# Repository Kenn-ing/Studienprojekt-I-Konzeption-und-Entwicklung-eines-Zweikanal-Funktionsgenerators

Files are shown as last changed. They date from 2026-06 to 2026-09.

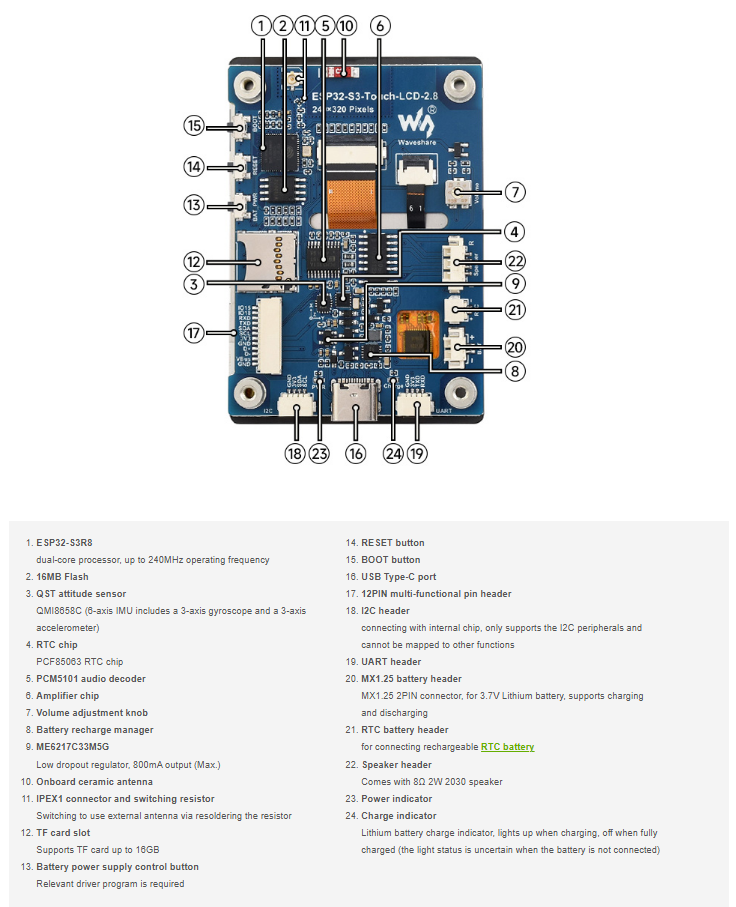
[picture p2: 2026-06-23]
docs/Pinouts/Waveshare ESP32-S3/Waveshare ESP32 S3 Ports.png

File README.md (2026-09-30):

# Studienprojekt-I-Konzeption-und-Entwicklung-eines-Zweikanal-Funktionsgenerators
 
Dieses Repository ist Teil des ersten Studienprojekts der Studenten **Dejan Dimitrijević** und **Alexander Klose** an der [**Hochschule für Wirtschaft und Recht (HWR) Berlin**](https://www.hwr-berlin.de/) in Zusammenarbeit mit den [**Berliner Wasserbetrieben AöR**](https://www.bwb.de/de/index.php).
 
| | |
|---|---|
| **Hochschulbetreuer** | Prof. Dr. Luís Fernando Ferreira Furtado |
| **Unternehmensbetreuer** | Dipl.-Ing. (FH) Thomas Freitag |
 
## Grundlegende Informationen
 
Dieses GitHub-Repository befasst sich mit der Konzeption und Entwicklung zweier Zweikanal-Funktionsgeneratoren auf Basis eines [Waveshare ESP32-S3 2,8-Zoll-Touch-LCD-Displays](https://www.waveshare.com/wiki/ESP32-S3-Touch-LCD-2.8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). Die Funktionsgeneratoren geben auf zwei Kanälen (A und B) sinus- und rechteckförmige Spannungssignale mit einstellbarer Frequenz, Amplitude und Phasenverschiebung aus. Über das Display können verschiedene Gruppen mit jeweils individuellen Parametern ausgewählt werden. Zusätzlich zur Gruppenauswahl sind Hilfestellungen zur Verwendung der Laborgeräte in die Benutzeroberfläche integriert.
 
Die Gruppenparameter für Amplitude, Frequenz, Phasenverschiebung und Signalform werden über eine CSV-Datei, die auf einer microSD-Karte gespeichert wird, eingelesen. Im Rahmen des Projekts wurden zwei unterschiedliche Implementierungsmethoden entwickelt und gegenübergestellt.
 
## Implementierungsmethode A: Signalgenerierung mittels interner Digital-Analog-Wandler eines ESP32
 
- Ausgabe der analogen Spannungswerte über die DAC-Ausgänge eines [ESP32 DevKit C V4](https://www.az-delivery.de/products/esp32-dev-kit-c-v4-nodemcu-wlan-wifi-development-board-mit-usb-c-anschluss-kompatibel-mit-arduino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), welcher per UART vom ESP32-S3 angesteuert wird.
- Die benötigten Parameter werden per UART übermittelt. Aus diesen wird ein Spannungssignal berechnet und über die internen DAC-Pins ausgegeben.

## Implementierungsmethode B: Signalgenerierung mittels Direct Digital Synthesis
 
- Ausgabe der unterschiedlichen Spannungssignale mittels zwei [AD9833-DDS-ICs](https://asset.conrad.com/media10/add/160267/c1/-/en/002993328DS00/datenblatt-2993328-analog-devices-ad9833brmz-reel7-schnittstellen-ic-dds-direct-digital-synthesizer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).
- Zur Anpassung der Ausgangsamplitude wird die Eingangsspannung eines [OPA1612](https://www.ti.com/lit/ds/symlink/opa1612.pdf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)-Operationsverstärkers über zwei digitale Potentiometer des Typs [MCP42010](https://cdn-reichelt.de/documents/datenblatt/A200/MCP42010_MIC.pdf) gesteuert.

## Repository-Struktur
 
```
├── sw/
│   ├── libraries/
|       └── lvgl/                       # lvgl Treiber
|       └── Adafruit_NeoPixel/          # NeoPixel/ws2812b Treiber
│   └── DAC_Prog/                       # Implementierungsmethode A
|       └── ESP32DevMod/                # Code für die Steuerung der Komponenten und Ausgabe der Spannung
|       └── ESP32S3/                    # Code für die Benutzeroberfläche und das Einlesen des Parameter
│   ├── DDS_Prog/                       # Implementierungsmethode B
|       └── ESP32DevMod/                # Code für die Steuerung der Komponenten und Ausgabe der Spannung
|       └── ESP32S3/                    # Code für die Benutzeroberfläche und das Einlesen des Parameter
├── proj/
│   └── EEZ Studio Projekt/             # Allgemeines EEZ Studio Projekt der Benutzeroberfläche
├── docs/
│   ├── SP-I_Klose_Dimitrijevic.pdf     # Schriftliche Ausarbeitung inklusive aller verwendeten Quellen
│   ├── Schaltpläne/                    # Schaltpläne der beiden Methoden
│   └── 3D-Design/                      # 3D Dateien und technische Zeichnungen der Gehäuse
│   └── Datenblätter/                   # Datenblätter der Komponenten
│   └── Pinouts/                        # Pinouts der Komponenten
└── README.md
```
 
## Installation
 
1. **Arduino IDE** mit [Unterstützung für ESP32 installieren](https://docs.waveshare.com/ESP32-Arduino-Tutorials/Arduino-IDE-Setup).
2. LVGL Bibliothek aus diesem Projekt herunterladen und in den `Arduino\libraries` Pfad kopieren.
3. Adafruit NeoPixel Bibliotheken aus diesem Projekt herunterladen und in den `Arduino\libraries` Pfad kopieren.
4. Je nach gewünschter Implementierungsmethode den entsprechenden Ordner ([`DAC_Prog`](https://github.com/Kenn-ing/Studienprojekt-I-Konzeption-und-Entwicklung-eines-Zweikanal-Funktionsgenerators/tree/main/sw/DAC_Prog) oder [`DDS_Prog`](https://github.com/Kenn-ing/Studienprojekt-I-Konzeption-und-Entwicklung-eines-Zweikanal-Funktionsgenerators/tree/main/sw/DDS_Prog)) in der Arduino IDE öffnen, das passende Board auswählen und flashen.
   - Für das ESP32-S3-Display müssen folgende Einstellungen in der Arduino IDE vorgenommen werden:
     - **Board:** ESP32S3 Dev Module
     - **USB CDC On Boot:** Enabled 
     - **Flash Size:** 16MB
     - **Partition Scheme:** 16M Flash (3MB APP/9.9MB FATFS)
     - **PSRAM:** OPI PSRAM
   - Für das ESP32 DevKit C V4 müssen folgende Einstellungen Arduino IDE vorgenommen werden:
     - **Board:** ESP32 Dev Module

## Nutzung
 
1. CSV-Datei mit den gewünschten Parametern für alle 30 Gruppen auf eine microSD-Karte kopieren und in das Display-Board einlegen.
3. System einschalten und die Daten nach dem die microSD-Karte erkannt wurde über den Button *Daten Laden* die Gruppenparameter einlesen.
4. Gewünschte Gruppe über die  Scroll-Liste auswählen, um das entsprechende Signal auf den Kanälen A und B auszugeben.
5. Über den Button *Start* die Signalausgabe starten.
6. Über den Button *Stop* die Signalausgabe stopen.
7. Über den Button *Hilfe* kann die Navigationsansicht aufgerufen werden, um zwischen den Hilfestellungen zu navigieren.
8. Uber den Zurück-Button in der oberen rechten Ecke gelangt man von jeder Unterseite zurück in die Navigationsansicht und von der Navigationsansicht zurück auf den Hauptbildschirm.

## Grenzwerte

| Variante | Frequenzbereich (Sinus)| Amplitudenbereich (Sinus)| Frequenzbereich (Rechteck)| Amplitudenbereich (Rechteck)|
|---|---|---|---|---|
| Implementierungsmethode A | `100 Hz - 500 Hz` | `500 mV - 1 V` | `10 Hz - 100 Hz` | `300 mV - 1,1 V` |
| Implementierungsmethode B | `1 kHz - 80 kHz` | `0,5 V - 10 V` | `10 kHz - 80 kHz` | `2 V - 10 V` |

## CSV-Dateiformat

| Spalte | Beschreibung | Einheit / Wertebereich | Beispiel |
|---|---|---|---|
| `Gruppe` | Fortlaufende ID der Parametergruppe | Ganzzahl | `1` |
| `Amplitude CH1` | Ausgangsamplitude auf Kanal 1 | mV | `410` |
| `Frequenz CH1` | Ausgangsfrequenz auf Kanal 1 | Hz | `1000` |
| `Phase CH1` | Phasenverschiebung auf Kanal 1 | ° (Grad) | `0` |
| `Signalform CH1` | Signalform für Kanal 1 | `0` = Sinus, `1` = Rechteck | `0` |
| `Amplitude CH2` | Ausgangsamplitude auf Kanal 2 | mV | `830` |
| `Frequenz CH2` | Ausgangsfrequenz auf Kanal 2 | Hz | `1000` |
| `Phase CH2` | Phasenverschiebung auf Kanal 2 | ° (Grad) | `11` |
| `Signalform CH2` | Signalform für Kanal 2 | `0` = Sinus, `1` = Rechteck | `0` |

**Beispielzeilen:**

```csv
Gruppe,Amplitude CH1,Frequenz CH1,Phase CH1,Signalform CH1,Amplitude CH2,Frequenz CH2,Phase CH2,Signalform CH2
1,410,1000,0,0,830,1000,11,0
2,830,1500,0,0,1650,45,27,0
3,240,2000,0,0,620,56,29,0
```

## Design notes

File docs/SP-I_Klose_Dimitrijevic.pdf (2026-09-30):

Studienprojekt I

### Konzeption und Entwicklung eines Zweikanal-Funktionsgenerators auf Basis eines Waveshare ESP32-S3 2,8-Zoll-Touch-LCD-Displays

Name, Vorname: | Klose, Alexander Linus
Matrikelnummer: | 77201148558
Name, Vorname: | Dimitrijevic, Dejan ´
Matrikelnummer: | 77203661440
Jahrgang: | 2024
Hochschule – Fachbereich: | HWR Berlin – Duales Studium - Technik
Fachrichtung: | Elektrotechnik
Modul: | IE-M26-6045 Studienprojekt I
Betreuer Hochschule: | Prof. Dr. Luís Fernando Ferreira Furtado
Unternehmen: | Berliner Wasserbetriebe AoR¨
Betreuer Unternehmen: | Dipl.-Ing. (FH) Thomas Freitag

Zur Kenntnis genommen:

Datum/Unterschrift Studierender

Datum/Unterschrift Unternehmensbetreuer

Datum/Unterschrift Studierender

13.07.2026

13.07.2026

20.07.2026 i.A.

Studienprojekt I | 13. Juli 2026
Ehrenwortliche Erkl ¨ | arung ¨
Wir erklaren ehrenw ¨ | ortlich: ¨
1. dass wir unser Studienprojekt selbstandig verfasst haben, ¨
2. dass wir die Ubernahme w ¨ | ortlicher Zitate aus der Literatur sowie die Verwendung der Gedanken ¨

anderer an den entsprechenden Stellen innerhalb der Arbeit gekennzeichnet haben und

3. dass wir unser Studienprojekt bei keiner anderen Prüfung vorgelegt haben.

Wir sind uns bewusst, dass eine falsche Erklarung rechtliche Folgen haben wird. ¨

Datum/Unterschrift Studierender

Datum/Unterschrift Studierender

I

13.07.2026

13.07.2026

Kurzfassung

Die Hochschule für Wirtschaft und Recht Berlin (HWR Berlin) ist eine der großen Hochschulen Berlins und bietet mit einem Portfolio von 57 Studiengangen eine große fachliche Bandbreite. Mit ¨ dem Studiengang der industriellen Elektrotechnik bietet die HWR Studierenden die Moglichkeit, ¨ eine der altesten Disziplinen im Bereich der Ingenieurswissenschaften zu erlernen. ¨

Ein essenzielles Themengebiet der Elektrotechnik stellt die Messtechnik dar. Im Studium werden die Inhalte sowie der Umgang mit Messgeraten frühzeitig vermittelt. Das vermittelte Wissen wird ¨ gegen Ende des Semesters durch eine Laborprüfung überprüft. Im Rahmen der Uberarbeitung des ¨

Moduls Messtechnik I (ET2013) soll der aktuell verwendete Funktionsgenerator (HAMEG HM 8030-4) zukünftig durch einen Zweikanal-Funktionsgenerator auf Basis eines Waveshare ESP32-S3 2,8-Zoll-Touch-LCD-Displays ersetzt werden. Dieser soll in der Lage sein, vordefinierte Parameter für Amplitude, Frequenz, Phasenverschiebung und Signalform über eine CSV-Datei zu importieren und die entsprechenden Signale an den Ausgangen bereitzustellen. ¨

Im Entwicklungsprozess wurden zwei Implementierungsmethoden, die unterschiedliche Architekturen für die Signalgenerierung verwenden, betrachtet und anschließend verglichen. Die Implementierungsmethode A nutzt für die Erzeugung der Spannungssignale die internen 8-Bit-Digital-Analog-Wandler (DAC) eines zweiten Mikrocontrollers (ESP32 DevKit C V4) und berechnet die DAC-Stützwerte rein softwaretechnisch. Die Implementierungsmethode B basiert auf der Direct Digital Synthesis (DDS) und verwendet zwei DDS-ICs (AD9833) in Kombination mit zwei digitalen Potentiometermodulen (MCP42010) und einem Operationsverstarker (OPA1612), um zwei ¨ einstellbare Spannungssignale zu erzeugen.

Beide Methoden sind in ihrer Bedienung, der Benutzeroberflache sowie in der ¨ | Ubertragung der Pa- ¨

rameter mittels UART vom HMI (Master) an einen Slave-ESP32, welcher bei beiden Methoden die Spannungsausgabe steuert, identisch. Die Varianten unterscheiden sich jedoch in ihrer Schaltungsund Softwarekomplexitat sowie in den Kosten, Abmessungen und ihrer Genauigkeit. Als bewer- ¨ tende Kriterien wurden die Erfüllung der funktionalen und nicht-funktionalen Anforderungen mit besonderem Fokus auf die Vorgaben für die Spannungsgenauigkeit (≤ ±5 %), Phasengenauigkeit (≤ ±2°) und Frequenzgenauigkeit (≤ ±5 %) herangezogen. Bei der Gegenüberstellung der Mess-

ergebnisse beider Implementierungsvarianten hat sich gezeigt, dass Implementierungsmethode B eine deutlich bessere Genauigkeit und einen deutlich großeren Frequenz- sowie Spannungsbereich ¨ aufweist (Sinus: 1 kHz - 80 kHz bei einem Amplitudenbereich von 0,5 V - 10 V, Rechteck: 10 kHz
- 80 kHz bei einem Amplitudenbereich von 2 V - 10 V). Variante A besitzt hingegen einen deutlich kleineren Frequenz- sowie Spannungsbereich (Sinus: 100 Hz - 500 Hz bei einem Amplitudenbereich von 0,5 V - 1 V, Rechteck: 10 Hz - 100 Hz bei einem Amplitudenbereich von 0,3 V -1,1 V).

Anhand aller betrachteten Gesichtspunkte ist abschließend festzuhalten, dass die Methode B trotz
der hoheren Kosten, der gr ¨ | oßeren Schaltungs- und Softwarekomplexit ¨ | at sowie der gr ¨ | oßeren Ab- ¨
messungen besser für den Einsatz im Modul Messtechnik I ET2013 geeignet ist. Methode A stellt hingegen eine geeignete Losung für Anwendungen mit geringeren Anforderungen an Genauigkeit ¨ und Funktionsumfang dar, bei denen ein besonders kompaktes Gerat erforderlich ist. ¨

II

Inhaltsverzeichnis

1 Einleitung | 1
2 Stand der Technik | 3
3 Anforderungen und Rahmenbedingungen | 6
4 Konzept und Systemarchitektur | 11

### 5 Implementierungsmethode A: Signalgenerierung mittels interner Digital-Analog-Wandler

eines ESP32 | 16
6 Implementierungsmethode B: Signalgenerierung mittels Direct Digital Synthesis | 27
7 Entwicklung der Benutzeroberflache | 43 ¨

III

7.2 Umsetzung mittels EEZ Studio und der LVGL-Library | | 43
8 Mechanisches Design | 45
8.1 Konstruktion | | 45
8.2 Materialauswahl und Fertigung | | 46
9 Fazit | 47
9.1 Vergleich | | 47
9.2 Bewertung und Empfehlung | | 49
Quellenverzeichnis | 51
Anhang | 55

IV

### 1. Einleitung

Die Metropolregion Berlin zahlt zu den bedeutendsten Wissenschaftsstandorten der Welt. Ihre ¨ Geschichte ist gepragt von Namen wie Planck, Humboldt und Einstein. Ihre heutige Stellung ¨ in der Forschung und Lehre verdankt sie den insgesamt vier Universitaten, sieben Hochschulen ¨
und über 70 außeruniversitaren Forschungseinrichtungen. ¨ | Uber 200.000 Studierende aus In- und ¨

Ausland leben und lernen in Berlin. Mit rund 12.000 Studierenden ist die Hochschule für Wirtschaft und Recht Berlin (HWR Berlin) eine in der Hochschullehre fest verankerte Große. Sie ist eine der ¨ bedeutendsten Hochschulen Berlins und bietet mit einem Portfolio von 57 Studiengangen eine große ¨ fachliche Bandbreite. Von Wirtschaftswissenschaften über Rechts- und Sicherheitsmanagement bis hin zu ingenieurwissenschaftlichen Studiengangen bietet die HWR einen engen Praxisbezug, ¨
vielfaltige Forschung, hohe Qualit ¨ | atsstandards und eine starke internationale Ausrichtung. [1] ¨

Mit dem Studiengang der industriellen Elektrotechnik bietet die HWR die Moglichkeit, eine der ¨ traditionsreichsten Fachrichtungen der Ingenieurwissenschaften zu erlernen. Im Vordergrund steht dabei die praktische Anwendbarkeit des vermittelten Wissens. Die Studierenden sollen befahigt ¨ werden, an der Entwicklung elektronischer bzw. elektrotechnischer Produkte sowie an der Planung und Leitung von Projekten der Automatisierungstechnik und Energietechnik mitzuwirken. Neben den technischen spielen dabei ebenfalls die wirtschaftlichen Aspekte stets eine zentrale Rolle. [2,
S. 3]

Bereits im ersten Semester begegnet den Studierenden im Studiengang der industriellen Elektrotechnik das Modul Messtechnik I (ET2013). Im Rahmen dieses Moduls erwerben die Studierenden tiefgreifende Kenntnisse im Umgang mit Messinstrumenten, in grundlegenden Aspekten der Planung und Realisierung von Messaufbauten sowie in der Durchführung von Fehleranalysen zur Bestimmung der resultierenden Messabweichungen. Um dieses Wissen vermitteln zu konnen, wer- ¨ den die Grundbegriffe der Messtechnik wie SI-Einheiten, Kalibrieren, Abgleichen, relative und absolute Messabweichung definiert, in der Theorie aufgearbeitet und mit Ubungen gefestigt. Des ¨

Weiteren wird auf Fehlerarten, Fehlerfortpflanzung sowie Messwertanalysen eingegangen. Zum Ende des Semesters werden die in der Theorie erlernten Inhalte in einem Laborversuch praktisch überprüft. Durch die Erstellung einer Laborarbeit konnen die Studierenden die Ergebnisse unter ¨ wissenschaftlichen Gesichtspunkten auswerten und dokumentieren. Der Umgang mit Messgeraten ¨ wie Oszilloskopen und analogen bzw. digitalen Multimetern ist dabei essenziell. [2, S. 11]

Im Zuge der Neustrukturierung des Moduls, die ebenfalls eine Uberarbeitung der aktuellen ¨

Prüfungsleistung beinhaltet, werden die Studierenden zukünftig als Teil der Laborversuche verschiedene Spannungssignale unter zahlreichen Gesichtspunkten messen und analysieren müssen. Um diesen Prozess für die große Anzahl an Arbeitsgruppen zu vereinfachen und zu standardisieren, soll auf die Verwendung eines klassischen Funktionsgenerators (Abbildung 1), der von den Studierenden manuell eingestellt werden muss, verzichtet werden. Stattdessen soll zukünftig ein Funktionsgenerator mit bereits vordefinierten Parametern für die einzelnen Gruppen und einer einfachen sowie benutzerfreundlichen Gruppenauswahl über ein Human-Machine-Interface (HMI) verwendet werden. [3]

Im Rahmen der nachfolgenden Arbeit werden der Entwurf, die Konzeption und der konstruktive

Aufbau eines solchen Funktionsgenerators auf der Grundlage eines Waveshare ESP32-S3 2.8-Zoll-Touch-LCD-Displays dokumentiert. Der Fokus der Ausarbeitung liegt dabei auf der Darstellung
des Designprozesses sowie der Probleme und Losungsans ¨ | atze bei der Entwicklung des Ger ¨ | ats. Dies ¨
umfasst ebenfalls die ausführliche Durchführung von Tests zur Validierung der Funktionsweise und den Vergleich zweier Konzepte zur Signalgenerierung unter Berücksichtigung konkreter Parameter wie der Signalqualitat, Genauigkeit und Wirtschaftlichkeit. Bei diesen zwei Konzepten handelt es ¨ sich konkret um die Signalgenerierung mittels interner Digital-Analog-Wandler (DAC) eines ESP32 und der Signalgenerierung mittels externer Direct Digital Synthesis (DDS) ICs.

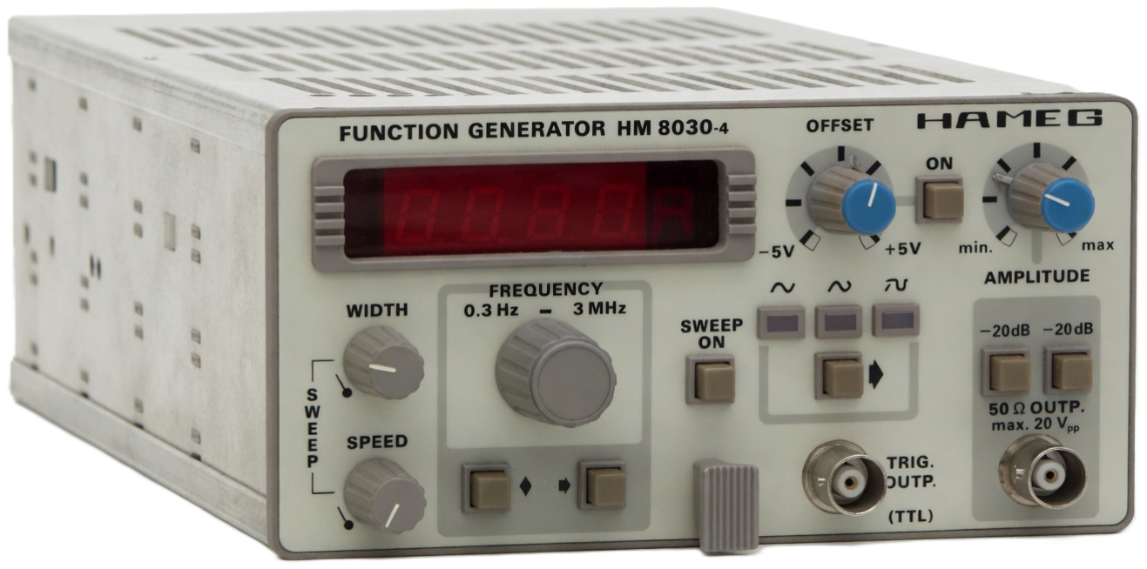
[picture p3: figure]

Abbildung 1: Aktuell verwendeter Funktionsgenerator im Messtechniklabor der HWR Berlin am Standort Lichtenberg (E-Labor 6B.158) (HAMEG HM 8030-4)[4]

### 2. Stand der Technik

### 2.1. Human-Machine-Interfaces (HMIs) in der Industrie

Im Zuge der Industrie 4.0 sind intelligente Maschinen und digitale Technologien aus modernen Produktionsumgebungen nicht mehr wegzudenken. Eine zentrale Rolle nehmen dabei HMIs ein. Durch
das Zusammenspiel von Hardware und Software ermoglichen sie dem Nutzer die ¨ | Uberwachung ¨

von Prozessen, die Visualisierung von Anlagenzustanden sowie die Anpassung relevanter Para- ¨ meter. Typische Anwendungsbeispiele reichen von der Steuerung eines Forderbandes bis hin zur ¨ Regelung der Temperatur eines Wassertanks. [5, S. 2-3]

In industriellen Anlagen werden HMIs in der Regel nicht isoliert, sondern als Bestandteil eines übergeordneten Supervisory Control and Data Acquisition (SCADA) Systems eingesetzt. Ein solches System dient der Steuerung und Uberwachung umfangreicher Anlagen oder ganzer Standorte ¨

und erfasst zugleich samtliche betriebsrelevante Daten. Das System kombiniert verschiedene Teil- ¨ systeme wie speicherprogrammierbare Steuerungen (SPS), Sensoren und Remote Terminal Units (RTUs), wahrend das HMI die Schnittstelle zwischen Nutzer und Gesamtsystem bildet. [5, S. 3] ¨ Ein praxisnahes Beispiel ist der Einsatz von HMIs bei den Berliner Wasserbetrieben (BWB). Sie
visualisieren die Fordermenge sowie die Anzeige von Pumpenzust ¨ | anden und Fehlermeldungen. ¨
[6, S. 73]

### 2.2. Mikrocontroller und Embedded-Plattformen anhand der ESP32-Familie

Mikrocontroller stellen den vorlaufigen Abschluss einer Entwicklung digitaler Logiksysteme dar, ¨ welche das grundlegende Ziel der Loslosung von der starren Verdrahtung der logischen Funktio- ¨ nen verfolgte. Diese Entwicklung begann bereits im Jahr 1965 mit der fest verdrahteten Logik oder auch hardwired logic. Hierbei wurden logische Funktionen und komplizierte sequenzielle Ablaufe ausschließlich mittels der festen Verdrahtung von Bauelementen wie Gattern, Flipflops ¨ und Schieberegistern realisiert. Das Programm ergab sich also aus der Verdrahtung der einzelnen Komponenten. Der Hauptnachteil dieses Logiktyps liegt darin, dass die logischen Funktionen bzw.
das Programm eines fertiggestellten Aufbaus kaum oder nur sehr umstandlich ver ¨ | anderbar sind. ¨
Jede Anpassung war mit enormem Aufwand und Arbeitszeit verbunden. [7, S. 1]

Mit der Entwicklung der ersten Halbleiterspeicher ROM (read only memory) und RAM (random access memory) um das Jahr 1972 wurde die Entwicklung eines neuen Logiktyps moglich. Bei der ¨ sogenannten mikroprogrammierten Logik wird ein Teil des Programms in einem Festwertspeicher und nicht durch die reine Verdrahtung von Bauelementen realisiert. Gleichzeitig wurden immer mehr flexible digitale Bausteine entwickelt, die die mikroprogrammierte Logik weiter unterstützten. [7, S. 1-2]

Durch die Entwicklung der Mikroprozessoren und Mikrocontroller im Jahr 1973 erreichte die Hardware einen universellen Charakter, wurde platzsparender und konnte in zahlreichen Geraten ¨ eingesetzt werden. Dabei liegen sowohl die Logik als auch die Sequenzen normalerweise im Programm, also der Software des Mikrocontrollers. Der Mikrocontroller ist dabei als ein hochintegrierter Baustein zu verstehen, der neben dem Mikroprozessor einen oder mehrere serielle und parallele Portbausteine, Datenspeicher und andere Sonderfunktionen an Hardware auf einem einzigen Chip vereint. Ein Mikrocontroller besitzt also im Gegensatz zum Mikroprozessor bereits zahlreiche Peripheriebausteine. Aufgrund des geringen Aufwands bezüglich des Hardwaredesigns eignen sich Mikrocontroller besonders für einfache Steuerungsaufgaben wie z. B. Aufzugs-, Waschmaschinen- und Steuerungen aller Art. Auch bei umfangreicheren Aufgaben, wie beispielsweise in Kraftfahrzeugen, finden sie Anwendung. [7, S. 2-3]

Im Bereich des Internet of Things (IoT) und in Embedded-Projekten haben sich in den letzten Jahren besonders Mikrocontroller der Firma Espressif Systems Company, welche sich als eine leistungsstarke und kostengünstige Plattform für die Entwicklung zahlreicher Anwendungen erwiesen haben, etabliert. [8] Seit der Markteinführung im Jahr 2016 vertreibt Espressif Systems seine Mikrocontroller überwiegend unter der Bezeichnung ESP32. [9]

Dabei bietet das Unternehmen zahlreiche Produktvarianten für unterschiedliche Anwendungsbereiche an. Neben den im Privatbereich weit verbreiteten Modulen wie dem ESP32-WROOM oder ESP32-MINI, die sich durch Xtensa-Prozessoren mit einem oder zwei Kernen, Taktfrequenzen von bis zu 240 MHz sowie zahlreiche Peripherieschnittstellen wie kapazitive Touchsensoren, Hall-Sensoren, Ethernet, SPI, UART, I²C und I²S auszeichnen, bietet Espressif Systems mit der

ESP32-S3-Serie ebenfalls Mikrocontroller für komplexere Anwendungen wie die Verarbeitung neuronaler Netze und die digitale Signalverarbeitung an. [10]

Durch Funktionen wie integrierte Wi-Fi- und Bluetooth-Konnektivitat, eine große Anzahl an ¨ General-Purpose-Input/Output-(GPIO)-Pins sowie die vergleichsweise hohe Rechenleistung eignen sich ESP32-Module besonders für anspruchsvollere Embedded-Projekte. [8]

### 2.3. Architekturen fur die Signalgenerierung ¨

Für die Generierung von Spannungssignalen haben sich über die Jahre einige Architekturen eta-
bliert. Sie unterscheiden sich primar in der realisierbaren Signalqualit ¨ | at, Frequenzaufl ¨ | osung, Kom- ¨
plexitat und den Kosten. Im einfachsten Fall wird ein periodisches Signal durch die softwarege- ¨ steuerte Ausgabe von vorberechneten Stützwerten über einen DAC erzeugt. [11, S. 1] In einigen
Mikrocontrollern sind solche DAC-Ausgange bereits integriert und ohne zus ¨ | atzliche Hardware ¨
nutzbar. [12, S. 45]

Eine leistungsfahigere Methode zur Signalerzeugung, die in den Bereichen der Nachrichtentechnik ¨ und allgemein in industriellen Anwendungen immer haufiger zum Einsatz kommt, ist die Direct ¨ Digital Synthesis. Bei der DDS erfolgen die Signalgenerierung und die Digital-Analog-Wandlung meist in einem einzigen dedizierten Baustein. Das Funktionsprinzip basiert auf einem Phasenakkumulator, der mit jedem Taktzyklus eines Referenztaktes um einen festen, digital programmierbaren Wert, das sogenannte tuning-word, inkrementiert wird. [11, S. 1] Gegenüber einer rein software-
basierten Losung bietet die DDS-Architektur dadurch eine deutlich feinere Frequenzaufl ¨ | osung, ein ¨
schnelles und phasenkontinuierliches Umschalten zwischen Frequenzen sowie eine hohe Unempfindlichkeit gegenüber Bauteilalterung und Temperaturveranderungen. [11, S. 3] ¨

Im Rahmen dieser Ausarbeitung werden genau diese zwei Varianten der Signalgenerierung unter verschiedenen Gesichtspunkten analysiert, miteinander verglichen und hinsichtlich ihrer Eignung für den Einsatz in einem Funktionsgenerator bewertet.

Eine detaillierte Beschreibung der Funktionsweise, des internen Aufbaus sowie der charakteristischen Kennwerte der einzelnen Verfahren zur Signalgenerierung erfolgt im Rahmen der jeweiligen Kapitel, welche die Umsetzung der jeweiligen Methoden behandeln (Kapitel 5 und Kapitel 6).

### 3. Anforderungen und Rahmenbedingungen

In den Nachfolgenden Abschnitten werden die Anforderungen bezüglich des zu entwickelnden Funktionsgenerators auf Grundlage des vorhandenen Prüfungsmaterials des Moduls Messtechnik I (ET2013) und die daraus entwickelten funktionalen und nicht-funktionalen Anforderungen beschrieben.

### 3.1. Anwendungsfall: Laborprufung ¨

Wie bereits in der Einleitung dieser Ausarbeitung erwahnt, durchl ¨ | auft das Modul Messtechnik ¨
I (ET2013) aktuell einer Neustrukturierung, die ebenfalls eine Uberarbeitung der Laborprüfung ¨

beinhaltet. Die neu entwickelten Aufgaben der Laborarbeit umfassen das Analysieren und Messen verschiedener sinus- sowie rechteckformiger Spannungssignale. Im Zuge dieser Aufgaben sollen ¨ die Studierenden zahlreiche Parameter bezüglich der verschiedenen Spannungssignale messen und berechnen. Diese Parameter sind in Tabelle 1 aufgelistet.

Konkret lauten die Aufgabenstellungen wie folgt:

•
”

Analysieren Sie die sinusformigen Spannungssignale im Oszilloskop in Kanal 1 und Kanal ¨ 2 und geben Sie die Messwerte gemaß der folgenden Tabelle ein:“ [13, S. 1] ¨
•
”

Analysieren Sie das rechteckformige Spannungssignal im Oszilloskop in Kanal 1 und geben ¨ Sie die Messwerte gemaß der folgenden Tabelle ein:“ [13, S. 2] ¨

Die Messwerte beziehen sich dabei auf die in Tabelle 1 angegebenen Parameter. Anhand dieser Parameter und Aufgabenstellungen konnten bereits zahlreiche funktionale Anforderungen aufgestellt ¨ werden. Neben den eigentlichen Aufgaben, welche die Studierenden im Rahmen der Laborarbeit erhalten und bearbeiten müssen, gibt es zudem eine vorgefertigte Tabelle, in welcher die unterschiedlichen Parameter der einzelnen Arbeitsgruppen bereits vordefiniert sind. Die einzelnen Arbeitsgruppen erhalten also nicht alle einheitliche Parameter, sondern jede Gruppe erhalt für jede ¨ Aufgabe individuelle Spannungssignale. Ein kleiner Ausschnitt aus den Tabellen für die sinussowie rechteckformigen Spannungssignale ist in den Tabellen 15 und 16 auf den Seiten 55 und 56 ¨ im Anhang zu finden. Da die Studierenden unter Verwendung des aktuellen Funktionsgenerators
die Spannungssignale selbststandig einstellen müssten, w ¨ | aren ihnen die tats ¨ | achlichen Werte bereits ¨
bekannt und ein Lerneffekt durch das gezielte Bestimmen mittels des Oszilloskops würde weitestgehend ausbleiben. Aufgrund dieser Tatsache soll der neu entwickelte Funktionsgenerator eine Moglichkeit bieten, die Spannungssignale mit den entsprechenden Werten der einzelnen Arbeits- ¨ gruppen ohne das eingreifen eines Studierenden auszugeben. Dies konnte beispielsweise über eine ¨ Comma-Separated-Values (CSV) -Datei oder über das Eingeben der einzelnen Parameter durch den Professor über eine serielle Verbindung mit einem beliebigen digitalen Endgerat erfolgen. Dabei ¨ würden die Werte für die Frequenz, Ausgangsspannung und Phasenverschiebung ohne das eingreifen der Studierenden festgelegt werden. Diese müssten nur über eine Bedienoberflache auf dem ¨ HMI ihre Arbeitsgruppe auswahlen und die Ausgabe des Spannungssignals starten und stoppen. ¨ Durch diese Struktur waren den Studierenden die vorgegebenen Parameter zu keinem Zeitpunkt ¨

Tabelle 1: Zu erhebende Messwerte der Studierenden bezüglich der sinus- sowie rechteckformigen ¨ Spannungssignale als Teil der Laborarbeit des Moduls Messtechnik I (ET2013) [13, S. 1-2]

sinusformige Spannungssignale ¨

T | Periodendauer
f | Frequenz
ω | Kreisfrequenz
u | Offset (Mittelwert)
û | Scheitelwert (max)
uˇ | Scheitelwert (min)
Ue | Spitze-Tal-Wert
Urms | Effektivwert
Δt | Phasenverschiebung in Zeit von Kanal 2
| bezüglich Kanal 1
φ[°] | Phasenverschiebung in Grad von Kanal 2
| bezüglich Kanal 1
φ[r ad] | Phasenverschiebung in Radiant von Kanal 2
| bezüglich Kanal 1
φ[%] | Phasenverschiebung in Prozent von Kanal 2
| bezüglich Kanal 1

rechteckformige Spannungssignale ¨

T | Periodendauer
f | Frequenz
ω | Kreisfrequenz
Δu = uˇ − 0 V | Offset von Null
û | Scheitelwert (max)
uˇ | Scheitelwert (min)
Ue | Spitze-Tal-Wert
Urms | Effektivwert
τ | Impulsdauer
D = τ/T | Tastgrad in Prozent (%)

bekannt, wodurch eine Anpassung oder Manipulation der Messergebnisse durch die Studierenden
verhindert werden konnte. Dadurch w ¨ | are sichergestellt, dass jede Arbeitsgruppe ausschließlich ¨
mit den ihr zugewiesenen Signalparametern arbeitet, die Versuchsdurchführung unter vergleichba-
ren Bedingungen erfolgt und die Messergebnisse tatsachlich eigenst ¨ | andig durch die Studierenden ¨
mithilfe des Oszilloskops bestimmt werden.

### 3.2. Funktionale Anforderungen

Der in Abschnitt 3.1 beschriebene Anwendungsfall sowie die vorgegebenen Aufgabenstellungen ermoglichen die Aufstellung zahlreicher funktionaler und nicht-funktionaler Anforderungen. Da ¨ sich aus den Aufgabenstellungen und den Messwerttabellen jedoch nicht alle Zielanforderungen ableiten lassen, wurde beschlossen, diese durch weitere essenzielle Punkte zu erganzen. Darunter ¨ fallen beispielsweise die Einbindung von Hilfestellungen zur Anwendung der Laborgerate (FA-12) ¨ und das Speichern der Gruppenparameter in einem Zwischenspeicher für den Fall, dass der Funktionsgenerator abstürzt oder ausgeschaltet werden sollte (FA-11). Für die Validierung der Genauigkeit und der Funktion der Funktionsgeneratoren werden dabei folgende Messwerte herangezogen: die Amplitude der Spannungssignale (entspricht dem Scheitelwert û), die Phasenverschiebung in Grad zwischen den Signalen und die Frequenz der Spannungssignale. Die Implementierung eines variablen Offsets sowie eines variablen Tastgrads wird nicht durchgeführt. Die final aufgestellten funktionalen Anforderungen sind in Tabelle 2 aufgelistet.

Tabelle 2: Funktionale Anforderungen des Projekts

Requirement number | Beschreibung
FA-1: | Das System muss zwei unabhangige analoge Ausg ¨ | ange (Kanal A, ¨
Kanal B), welche gleichzeitig genutzt werden konnen, bereitstel- ¨ len.
FA-2: | Bei den analogen Ausgangssignalen der Kanale A und B soll es ¨
sich um null symmetrische sinusformige sowie rechteckf ¨ | ormige ¨
Signale handeln.
FA-3: | Der Funktionsgenerator soll in der Lage sein, auf beiden Kanalen ¨
die Frequenz des Signals zu verandern. ¨
FA-4: | Der Funktionsgenerator soll in der Lage sein, auf beiden Kanalen ¨
die Amplitude des Signals zu verandern. ¨
FA-5: | Zwischen den beiden Ausgangssignalen muss eine definierte Pha-
senverschiebung einstellbar sein.
FA-6: | Das System muss die Verwendung vordefinierter Parametersatze ¨
unterstützen. Ein Parametersatz umfasst mindestens:
- Gruppenidentifikation
- Frequenz Kanal 1
- Frequenz Kanal 2
- Amplitude Kanal 1
- Amplitude Kanal 2
- Phasenverschiebung
- Signalform
FA-7: | Der Funktionsgenerator soll über ein HMI mit Touch-Funktion
verfügen.
FA-8: | Uber die Benutzeroberfl ¨ | ache (HMI) muss ein schnelles Umschal- ¨

ten zwischen den einzelnen Gruppen, ohne, dass das System neu gestartet werden muss, moglich sein. ¨

Requirement number | Beschreibung
FA-9: | Die Festlegung der Parameter für die Ausgangssignale der einzel-
nen Gruppen erfolgt über eine Eingabe per UART, das Einlesen einer CSV-Datei oder vergleichbare Losungen für den Import von ¨
| Parametern.
FA-10: | Uber die Benutzeroberfl ¨ | ache muss die Ausgabe der Signale auf ¨
beiden Kanalen gestartet und gestoppt werden k ¨ | onnen. Dies kann ¨
beispielsweise über dedizierte Buttons umgesetzt werden.
FA-11: | Sollte das System ausgeschaltet werden oder abstürzen und es
werden keine neuen Daten über eine microSD-Karte oder UART übergeben, werden die Parameter der letzten Sitzung bzw. An-
| wendung verwendet.
FA-12: | Auf dem HMI konnen die Studierenden Hilfestellungen für die ver- ¨
wendeten Laborgerate erhalten. Zu diesen Hilfestellungen geh ¨ | oren ¨
beispielsweise das Messen der Phasenverschiebung, der Amplitude und der Frequenz mittels des Oszilloskops.
FA-13: | Für die Navigation auf dem HMI sind dedizierte Buttons oder
anderweitige Bedienelemente implementiert.

### 3.3. Nicht-funktionale Anforderungen

Neben den funktionellen Anforderungen wurden auf der Grundlage des in Kapitel 3.1 beschriebenen Laborversuchs zudem zahlreiche nicht-funktionale Anforderungen definiert. Diese wurden, genau wie die funktionalen Anforderungen, durch erganzende Parameter erweitert. Die final auf- ¨ gestellten nicht-funktionalen Anforderungen sind in Tabelle 3 aufgelistet.

Tabelle 3: Nicht-funktionale Anforderungen des Projekts

Requirement number | Beschreibung
NFA-1: | Amplitudenfehler ≤ ±5 %
NFA-2: | Phasenfehler ≤ ±2°
NFA-3: | Frequenzfehler ≤ ±5 %
NFA-4: | Einstellbarer Frequenzbereich mind. 10 Hz bis 10 kHz. Akzeptiert: Falls dieser Frequenzbereich nicht erreicht werden kann, sollte der Frequenzbereich so groß sein, dass für alle Gruppen unterschied- liche Frequenzen festgelegt werden konnen. ¨

Requirement number | Beschreibung
NFA-5: | Der einstellbare Spannungsbereich muss es ermoglichen, dass für ¨
alle Gruppen unterschiedliche Amplitudenwerte festgelegt werden
| konnen. ¨
NFA-6: | Touch-Eingaben müssen in weniger als 100 ms für den Benutzer
| sichtbar umgesetzt und an den Ausgangen wirksam sein. ¨
NFA-7: | Der Funktionsgenerator muss einen stabilen Betrieb ohne Absturz
| oder Neustart ermoglichen. ¨
NFA-8: | Bei fehlerhaften Eingabedateien oder Hardwarefehlern fallt das ¨
| Gerat in einen definierten sicheren Zustand und es wird eine ein- ¨ deutige Fehlermeldung angezeigt.
NFA-9: | Die Stromversorgung wird über ein Netzteil oder optional über
| einen internen Akku geregelt. Falls ein Akkubetrieb vorgesehen ist:

Die Laufzeit sollte ≥ 2 h bei typischer Nutzung betragen. Zudem sollte ein Batteriemanagementsystem (BMS) implementiert sein.

NFA-10: | Der Programmcode ist strukturiert und modular aufgebaut. Einzel-
| ne Funktionen sind, um die Verstandlichkeit zu verbessern, durch ¨ Kommentare beschrieben. Die Modularitat des Programmcodes ¨ ermoglicht sowohl Wiederverwendbarkeit als auch Skalierbarkeit. ¨
NFA-11: | Der Funktionsgenerator besitzt ein labortaugliches Gehause mit ¨
eindeutiger Beschriftung der einzelnen Anschlüsse und guter Be-
| dienbarkeit.
NFA-12: | Die Hinweise zur Anwendung der Laborgerate sind verst ¨ | andlich ¨
| und gut lesbar.

### 4. Konzept und Systemarchitektur

### 4.1. Komponentenubersicht (Waveshare ESP32-S3) ¨

Das Waveshare ESP32-S3-Touch-LCD-2.8 bildet die zentrale Steuer- und Bedieneinheit des entwickelten Funktionsgenerators. Das Board basiert auf dem ESP32-S3R8-Mikrocontroller von Espressif Systems, der einen Xtensa 32-Bit LX7 Dual-Core-Prozessor mit einer Taktfrequenz von bis zu 240 MHz besitzt. Der verfügbare Arbeitsspeicher umfasst 512 KB SRAM sowie 8 MB PSRAM, erganzt durch 16 MB Flash-Speicher für die dauerhafte Ablage von Programm- und ¨ Konfigurationsdaten. [15, S. 1-2.]

Das Board verfügt über ein integriertes 2,8-Zoll-IPS-Display mit einer Auflosung von 240 ¨ | ×320 Pi-

xeln und einem kapazitiven Touchscreen, der 5-Punkt-Touch über die I²C-Schnittstelle unterstützt.

In der Abbildung 2 ist das Board in der Front- und Rückansicht abgebildet. Die Kombination aus Display und Touchscreen ermoglicht die Realisierung einer intuitiven und benutzerfreundlichen ¨ Mensch-Maschine-Schnittstelle. Darüber hinaus unterstützt das Board die Light and Versatile Graphics Library (LVGL), wodurch die Entwicklung einer strukturierten, leistungsfahigen und reak- ¨
tionsschnellen grafischen Benutzeroberflache ohne zus ¨ | atzliche Hardwarekomponenten erm ¨ | oglicht ¨
wird. [15, S. 1]

Für die Anbindung externer Peripheriebausteine stehen GPIO-, UART- sowie I²C-Schnittstellen

über dedizierte Header-Anschlüsse auf der Rückseite des HMIs zur Verfügung. Zudem verfügt das Board über einen integrierten microSD-Karten-Slot, der über den SPI-Bus angesprochen wird. Dieser würde beispielsweise das Einlesen der gruppenspezifischen Parameterdatei im CSV-Format
ermoglichen. [15, S. 2-3] Die Pinbelegung sowie alle Anschlussm ¨ | oglichkeiten des Boards sind in ¨
Abbildung 3 übersichtlich dargestellt.

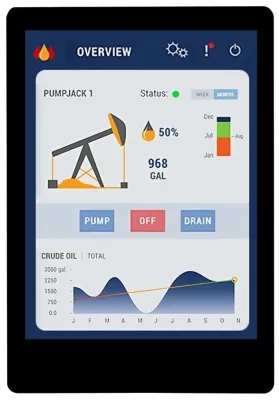
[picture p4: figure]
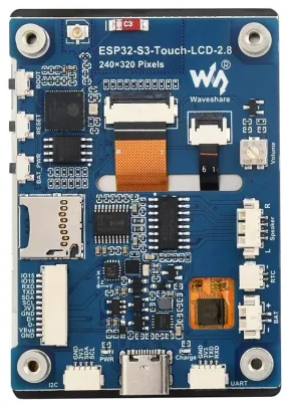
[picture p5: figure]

(a) HMI Frontansicht | (b) HMI Rückansicht

Abbildung 2: Waveshare ESP32-S3-Touch-LCD-2.8 [15, S. 5]

### 4.2. Architekturubersicht ¨

Für die Umsetzung des Funktionsgenerators wurde eine Master-Slave-Architektur, deren Aufbau in Abbildung 4 modellhaft dargestellt ist, entwickelt. Das Waveshare-HMI-Modul verfügt zwar über umfangreiche Peripherie zur Anbindung von Display, Touchcontroller und microSD-Karte, jedoch über keine für die Signalerzeugung nutzbaren DAC-Ausgange. Zudem sind durch die inter- ¨ nen Anbindungen die meisten GPIO-Pins des ESP32-S3 bereits belegt, sodass über die externen Header-Anschlüsse lediglich zwei freie GPIO-Pins (GPIO-15 und GPIO-18) verbleiben. [15, S. 5] Eine Realisierung der Signalerzeugung auf dem Master selbst, unter Verwendung externer Signalbausteine, ist daher nicht sinnvoll umsetzbar. Aus diesem Grund wird ein zweiter Mikrocontroller in das System integriert. Bei diesem handelt es sich um ein ESP32 DevKit mit zwei internen DAC-Pins an GPIO 25 und GPIO 26. Die Kommunikation zwischen beiden Controllern erfolgt über eine UART-Schnittstelle, sodass der Master den Slave durch die Ubergabe der gruppenspezifischen ¨

Parameter ansteuern kann.

Aus dieser Aufteilung ergeben sich drei wesentliche Vorteile. Erstens entsteht eine klare funktionale Trennung zwischen Bedienlogik und Signalerzeugung, wodurch beide unabhangig voneinander ¨
entwickelt und getestet werden konnen. Zweitens wird die Echtzeitf ¨ | ahigkeit des Systems verbessert, ¨
da die zeitkritische Signalausgabe nicht durch Touch-Ereignisse oder das Rendern der grafischen
Benutzeroberflache unterbrochen wird. Drittens erh ¨ | oht die Aufteilung die Modularit ¨ | at des Ge- ¨
samtsystems. Der Master bleibt für unterschiedliche Implementierungsansatze identisch, w ¨ | ahrend ¨
die Signalerzeugung auf der Slave-Seite ausgetauscht werden kann.

Die Rollenverteilung ergibt sich somit unmittelbar aus diesem Konzept. Der Master übernimmt


Abbildung 3: Pinbelegung und Anschlussmoglichkeiten des Waveschare ESP32-S3-Touch-LCD- ¨ 2.8 [16]

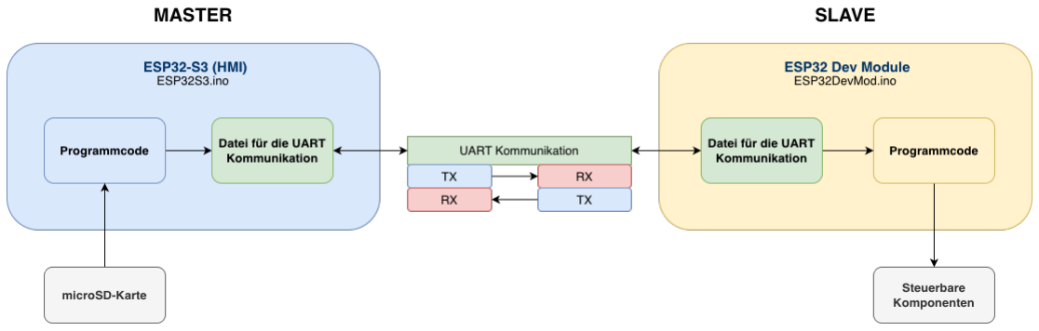
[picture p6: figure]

Abbildung 4: Modellhafte Darstellung des Master-Slave-Prinzips

die Darstellung der Benutzeroberflache, das Einlesen und Verarbeiten der Parameterdatei von ¨
der microSD-Karte sowie die Ubergabe der ausgew ¨ | ahlten Parameter an den Slave. Der Slave ¨
ist hauptsachlich für die Erzeugung der Spannungssignale gem ¨ | aß den empfangenen Vorgaben ¨
zustandig. ¨

### 4.3. Komponentenauswahl (ESP32 DevKit C V4)

Für die Realisierung der Signalerzeugung wurde das ESP32 DevKit C V4 der Firma AZ-Delivery (Abbildung 5) als zweiter Mikrocontroller ausgewahlt. Das DevKit basiert auf dem ESP32- ¨ WROOM-32-Modul, welches eine Taktfrequenz von bis zu 240 MHz besitzt. Der verfügbare Arbeitsspeicher umfasst 520 KB SRAM, erganzt durch 4 MB SPI-Flash für die Ablage von Pro- ¨ grammcode und Konfigurationsdateien. [17, S. 2]

Entscheidend für die Auswahl dieses Moduls sind die beiden 8-Bit-Digital-Analog-Wandler an GPIO 25 und GPIO 26, die für die Umsetzung der in Kapitel 5 beschriebenen Implementierungsmethode A unverzichtbar sind. Da weder das Waveshare-HMI noch leistungsstarkere Varianten der ¨ ESP32-S3-Serie über derartige DAC-Ausgange verfügen, stellt das ESP32-WROOM-32-Modul ¨ innerhalb der ESP32-Familie eine technisch konsistente und zugleich kostengünstige Losung dar. ¨

Neben den DAC-Pins bietet das DevKit eine große Anzahl an frei verfügbaren GPIO-Pins sowie die

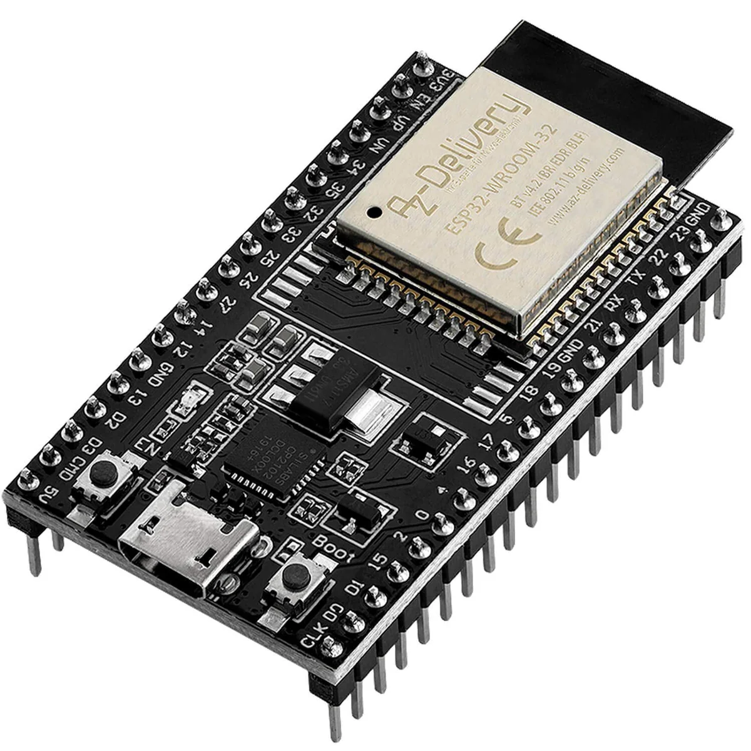
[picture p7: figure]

Abbildung 5: ESP32 DevKit C V4 der Firma AZ-Delivery [18]

für beide Implementierungsmethoden erforderlichen Schnittstellen. Uber die UART-Schnittstelle ¨

erfolgt der Empfang der gruppenspezifischen Parameter vom Master, wahrend die SPI-Schnittstelle ¨ in der in Kapitel 6 beschriebenen Implementierungsmethode B zur Ansteuerung der externen Komponenten genutzt wird. [17, S. 16-17] Mit einem Betriebsspannungsbereich von 3,0 V bis 3,6 V lasst sich das Modul direkt über die 3,3-V-Versorgung des Waveshare-Boards versorgen, ¨ sodass für den Slave keine eigenstandige Spannungsversorgung erforderlich ist. [17, S. 26] ¨

### 4.4. Datenubertragung zwischen Master und Slave ¨

Wie in Abschnitt 4.2 beschrieben, übernimmt der Master die Verwaltung der gruppenspezifischen Parameter, wahrend der Slave für die Erzeugung der Spannungssignale verantwortlich ist. Damit ¨ der Slave die Parameter ausgeben kann, müssen diese zunachst auf dem Master eingelesen und ¨ anschließend über die UART-Schnittstelle übergeben werden. Der gesamte Datenfluss gliedert sich in die drei Phasen: Einlesen, Verarbeitung und Ubertragung. ¨

Die Parameter der einzelnen Arbeitsgruppen werden auf einer microSD-Karte in einer CSV-Datei abgelegt. Jede Zeile beschreibt eine Arbeitsgruppe und enthalt neun durch Kommata getrennte Wer- ¨ te: die Gruppen-ID sowie jeweils Amplitude (in mV), Frequenz (in Hz), Phase (in °) und Signalform

(0 = SIN, 1 = SQU) für die beiden Kanale. Die erste Zeile der Datei dient als Header und enth ¨ | alt die ¨
Spaltenbezeichnungen. Tabelle 4 zeigt den Inhalt der verwendeten Datei mit drei Beispielgruppen. Die Wahl des CSV-Formats begründet sich durch dessen einfache Handhabung. Parametersatze ¨ lassen sich ohne großen Aufwand in einem beliebigen Tabellenkalkulationsprogramm (z.B. Excel) erstellen und anpassen. Zudem ist das zeilenorientierte Format ressourcenschonend, da wahrend ¨ des Einlesens stets nur eine Zeile im Arbeitsspeicher gehalten werden muss.

Sobald der Nutzer auf dem HMI die Funktion zum Laden der Parameter auslost, wird über ¨ den Master der SPI-Bus initialisiert, die Datei geoffnet und zeilenweise eingelesen. Dabei wird ¨ die Header-Zeile übersprungen und jede weitere Zeile wird in eine Datenstruktur des Typs SignalGroup überführt und in einem Array im Arbeitsspeicher des Masters abgelegt. Die eigentliche Zerlegung einer Zeile übernimmt die in Listing 1 auf Seite 57 im Anhang gezeigte Funktion csv parse line(). Sie wertet die Zeichenkette mittels csv read value() feldweise von links nach rechts aus und konvertiert die Werte je nach Datentyp über atof() bzw. atoi(). Vor dem Schreiben der Variablen wird die Struktur mittels memset() mit Nullwerten initialisiert. Die maximale Anzahl an Gruppen ist, um den Speicherverbrauch zu minimieren, durch die Konstante MAX GROUPS begrenzt.

Tabelle 4: Signalparameter – drei Beispielgruppen aus der CSV-Datei

CH1 | CH2
Gruppe | Ampl. | Freq. | Phase | Form | Ampl. | Freq. | Phase | Form
1 | 410 | 50 | 0 | 0 | 830 | 50 | 90 | 0
2 | 1500 | 100 | 0 | 1 | 1000 | 100 | 45 | 1
3 | 620 | 500 | 0 | 1 | 750 | 500 | 20 | 1

Nachdem die Parameter aller Gruppen eingelesen wurden, werden diese an den Slave übertragen. Das Ubertragungsprotokoll ist text- und zeilenbasiert aufgebaut. Sowohl der serielle Monitor des ¨

Masters als auch der des Slaves geben samtliche Nachrichten im Klartext aus, was die Fehlersuche ¨ wahrend der Entwicklung erheblich vereinfacht. ¨

Eine vollstandige ¨ | Ubertragung gliedert sich in drei Phasen: ¨
1. Ankundigung: ¨ | Der Master sendet die Nachricht COUNT:n, wobei n für die Anzahl der
folgenden Gruppen steht. Der Slave kann dadurch den erforderlichen Speicher reservieren
und überprüfen, ob die anschließende Ubertragung vollst ¨ | andig empfangen wurde. ¨
2. Parameter: Für jede Gruppe wird eine Zeile mit allen neun Parametern im Format

G:<id>,A1:<Wert>,F1:<Wert>,P1:<Wert>,S1:<Wert>,A2:... übertragen.

3. Abschluss: Mit der Nachricht DONE signalisiert der Master das Ende der Ubertragung. ¨

Alle Nachrichten werden vom Slave mit einem ACK (Acknowledge) oder NACK (Negative Acknowledge) quittiert. Der Master wartet für jeden gesendeten Datensatz maximal 500 ms auf eine
Bestatigung, bevor die ¨ | Ubertragung als fehlgeschlagen erkannt und abgebrochen wird. Durch die- ¨

sen Mechanismus kann ein nicht reagierender Slave identifiziert werden und eine Fehlermeldung kann ausgegeben werden.

Neben der Ubertragung der Gruppenparameter, werden zus ¨ | atzlich zwei weitere Befehle vom Master ¨

übermittelt. Mit dem Befehl START:<id> fordert der Master den Slave auf, die Signalausgabe für die Gruppe mit der angegebenen ID zu starten. Mit der Nachricht STOP soll die aktive Ausgabe beendet werden. Beide Befehle erwarten ein ACK vom Slave als Bestatigung. Diese Aufteilung der ¨ Kommunikation in einen einmaligen Initialisierungs- und einen wiederkehrenden Steuerungsteil vermeidet überflüssigen Datenverkehr wahrend der Nutzung, da die einmal übertragenen Parameter ¨ im Speicher des Slaves verbleiben und über die Gruppen-ID jederzeit angesprochen werden konnen. ¨ Abbildung 12 auf der Seite 59 im Anhang zeigt die Aufnahmen der drei Phasen einer vollstandigen ¨ Ubertragungssequenz. ¨

### 5. Implementierungsmethode A: Signalgenerierung mittels interner Digital-Analog-

Wandler eines ESP32

In diesem Kapitel wird die erste Methode zur Signalerzeugung vorgestellt. Ausgehend von der in Kapitel 4.2 beschriebenen Master-Slave-Aufteilung werden die Umsetzung des Kommunikationsprotokolls sowie die Generierung der Spannungssignale beschrieben. Der Schwerpunkt liegt auf der Uberprüfung der in Kapitel 3 erarbeiteten Anforderungen an das System. Die durchgeführten Tests ¨

bilden zugleich die Grundlage für den spateren Vergleich der beiden Implementierungsans ¨ | atze in ¨
Kapitel 9.

Die Verarbeitung der Parameter sowie die Ausgabe der Signale wurde softwareseitig in der Programmiersprache C++ umgesetzt. Als Entwicklungsumgebung wurde die Arduino IDE (Version 2.3.X) gewahlt. Diese bietet eine Vielzahl bereits vorhandener Bibliotheken und verfügt über eine ¨ große globale Nutzerbasis, wodurch sowohl die Entwicklung als auch die Fehlersuche erleichtert werden. [19]

### 5.1. Kommunikationsprotokoll und Schnittstellendesign

Wahrend in Abschnitt 4.4 der Datenfluss aus Sicht des Masters dargestellt wurde, beschreibt dieses ¨ Unterkapitel die slaveseitige Umsetzung des Protokolls auf dem ESP32 DevKit. Der Fokus liegt auf der Darstellung der Empfangslogik, dem Parsing der eingehenden Nachrichten sowie dem Zusammenspiel zwischen den UART-Schnittstellen.

Die Empfangslogik teilt sich beim Slave in zwei Zustande auf. Diese sind im Code durch die bool- ¨ sche Variable receiving realisiert worden. Im Grundzustand ist die Variable auf false gesetzt und wartet auf eine Count:<id>-Nachricht, die den Beginn einer neuen Parameterübertragung signalisiert. Mit dem Empfang der Nachricht setzt der Slave die Variable receiving auf true und beginnt, die einzelnen Gruppen einzulesen. Diese werden zunachst in einem internen Puffer ¨ zwischengespeichert. Nach Erhalt der Nachricht DONE ist die Ubertragung beendet und der Slave ¨

speichert alle Gruppenparameter im Non-Volatile Storage (NVS). Zuletzt wird der Slave wieder in den Grundzustand (receiving = false) zurückgesetzt.

Die Steuerbefehle START:<id> und STOP sind bewusst zustandsunabhangig implementiert. Sie ¨
greifen ausschließlich auf den NVS zu, in welchem die Datensatze gespeichert sind. Somit k ¨ | onnen ¨
diese Befehle immer verarbeitet werden und sind getrennt von der Datenübertragung. Diese Trennung ist die unmittelbare technische Umsetzung der Anforderung FA-11. Da die im NVS gespeicherten Daten auch nach einem Neustart oder einem Stromausfall verfügbar sind, kann der Master eine zuvor übermittelte Gruppe jederzeit erneut starten, ohne die Parameter ein zweites Mal übertragen zu müssen. Tabelle 5 fasst die vom Slave erkannten Nachrichten, die ausgeloste ¨ Reaktion sowie die jeweilige Quittierung zusammen.

Die eigentliche Uberführung einer empfangenen Parameterzeile in die in Abschnitt 4.4 eingeführte ¨

Datenstruktur SignalGroup übernimmt die Funktion parse group(). Sie verwendet einen festen sscanf-Format-String, der exakt die neun Felder einer Gruppenzeile beschreibt. Der Rückgabewert von sscanf entspricht der Anzahl der erfolgreich eingelesenen Felder und dient unmittelbar als

Tabelle 5: Verarbeitete Nachrichten des Slaves, ausgeloste Aktion und Quittierung. ¨

Nachricht | Aktion | Antwort
COUNT:<n> | Anzahl prüfen (0 < n ≤ MAX GROUPS), Zahler ¨ zurücksetzen, Zustand receiving = true | ACK / NACK
G:<id>,A1:...,S2:<Wert> | Zeile parsen, Werte in den RAM-Puffer übernehmen | ACK / NACK
DONE | Vollstandigkeit prüfen, RAM-Puffer in den NVS ¨ schreiben, Zustand receiving = false | ACK / NACK
START:<id> | Gruppe aus NVS laden, DAC-Ausgabe starten | ACK / NACK
STOP | DAC-Ausgabe beenden, Kanale auf den DAC- ¨ Mittelwert (128) zurücksetzen | ACK

Plausibilitatsprüfung. Werden nicht alle neun Felder erkannt, gilt die Zeile als ungültig, es wird ¨ eine Fehlermeldung über den seriellen Monitor ausgegeben und die Zeile an den Master mit einem NACK quittiert. Erst bei einer vollstandig erkannten Zeile werden die eingelesenen Werte in die ¨ Variablen der SignalGroup-Struktur übernommen. Listing 2 auf Seite 58 im Anhang zeigt die Funktion in ihrer im Quellcode vorliegenden Form.

Die SignalGroup-Strukturen werden jedoch nicht unmittelbar dauerhaft gespeichert. Eine zentrale Designentscheidung des Slaves besteht vielmehr darin, eingehende Gruppenzeilen zunachst ¨ in einem RAM-Puffer der festen Große ¨ MAX GROUPS zwischenzuspeichern und erst nach Empfang der abschließenden DONE-Nachricht in den NVS zu übernehmen. Dadurch bleibt der bisher gespeicherte Parametersatz auch dann unversehrt, wenn eine Ubertragung mitten in der Sequenz ¨

abbricht, beispielsweise weil das Verbindungskabel gelost wird oder der Master einen unerwarteten ¨
Reset durchlauft. Erst eine vollst ¨ | andige und fehlerfreie ¨ | Ubertragung führt zu einer Ver ¨ | anderung ¨

des persistenten Speichers. Diese Pufferung und Persistierung ist in der Datei save data.cpp umgesetzt.

Mit dem Empfang einer gültigen START:<id>-Nachricht endet der Aufgabenbereich des Kommunikationsteils. Die Funktion dac start output(), deren interne Funktionsweise in Abschnitt 5.3 ausführlich beschrieben wird, übernimmt die in der SignalGroup-Struktur enthaltenen Parameter und beginnt mit der Ausgabe der entsprechenden Spannungssignale an den beiden DAC-Pins.

### 5.2. Schaltungsentwicklung

In diesem Abschnitt wird der schaltungstechnische Aufbau der Implementierungsmethode A zur Signalerzeugung beschrieben. Der vollstandige Schaltplan ist in Abbildung 13 auf Seite 60 im ¨ Anhang zu finden.

Die Spannungsversorgung des HMIs betragt 5 V DC und erfolgt über die integrierte USB-C- ¨ Schnittstelle. Das HMI (Master) versorgt anschließend den Slave mit 3,3 V. Eine gemeinsame Masseverbindung zwischen den beiden Boards stellt das für die UART-Kommunikation erforderliche Bezugspotential sicher. Die UART-Pins des Masters, U0TXD (GPIO 43) und U0RXD (GPIO

44), sind mit den entsprechenden Pins des Slaves, U2TXD (GPIO 17) und U2RXD (GPIO 16), gekreuzt verbunden, sodass TX jeweils auf RX trifft.

Die internen DACs des ESP32 konnen keine negativen Spannungswerte ausgeben. Somit sind die ¨ Spannungssignale nicht symmetrisch um den Nullpunkt und weisen einen Gleichspannungsoffset auf. Deswegen ist an den beiden DAC-Ausgangen des Slaves je ein Keramik-Koppelkondensator ¨ mit einer Kapazitat von 100 nF in Reihe geschaltet. Diese entfernen den Gleichspannungsanteil ¨ des Ausgangssignals und zentrieren das Signal um den Nullpunkt, wie es in FA-2 gefordert ist.

Der Koppelkondensator bildet gemeinsam mit dem Eingangswiderstand des Oszilloskops von R = 1 MΩ einen Hochpassfilter erster Ordnung. [23, S. 22] Dessen Grenzfrequenz fg berechnet sich nach der Formel 1.

fg =

1

2π · R · C

=

1
2π · 1 MΩ · 100 nF
≈ 1, 59 Hz | (1)

Die Grenzfrequenz liegt damit unterhalb des in der NFA-4 festgelegten Nutzfrequenzbereichs. Die
Dampfung des Nutzsignals l ¨ | asst sich über den Amplitudengang des Hochpasses nach Formel 2 bei ¨
einer Frequenz von 10 Hz bestimmen. [25, S. 241-243]

A = 20 · log10

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
= 20 · log10

©
«

1
√︄
1 +
1,59 Hz

10 Hz 2

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
≈ −0,11 dB. | (2)
Die Dampfung ist somit ab einer Frequenz von etwa 10 Hz vernachl ¨ | assigbar. Lediglich im Bereich ¨
der niedrigsten getesteten Frequenz (1 Hz) ist mit einer merklichen Dampfung sowie einer durch den ¨ Hochpass verursachten Phasenverschiebung zu rechnen, was bei der Bewertung der Messergebnisse in Abschnitt 5.4 entsprechend zu berücksichtigen ist.

Die Wahl eines Keramikkondensators ist durch dessen geringe Eigenverluste (niedriger ESR), die hohe Verfügbarkeit sowie das stabile Frequenzverhalten begründet. Keramikkondensatoren weisen über einen weiten Frequenzbereich eine niedrige Impedanz auf, sodass das Wechselspannungssignal ohne nennenswerte Verfalschung übertragen wird. [24] ¨

Zusatzlich wurde zur Rückmeldung an den Anwender ein adressierbarer LED-Streifen des Typs ¨ WS2812B, der über GPIO 15 des Slaves angesteuert und für visuelles Feedback, sowie ein passiver Buzzer für akustische Rückmeldung, welcher über GPIO 15 des Masters angesteuert wird, integriert. Diese Komponenten dienen ausschließlich der Benutzerinteraktion und haben keinen Einfluss auf die Signalqualitat. Der adressierbare LED-Streifen signalisiert dem Anwender den ¨ aktuellen Ausgabezustand. Im Stopp-Zustand leuchtet er grün, sobald eine Gruppe gestartet und ein Spannungssignal ausgegeben wird, wechselt die Farbe auf Rot. Der Buzzer erzeugt einen Ton,
wenn eine Schaltflache auf dem Display bet ¨ | atigt wird, sowie wenn die microSD-Karte eingeführt ¨
oder entfernt wird.

### 5.3. Ansteuerungslogik

Die Implementierung der Signalerzeugung und Geratesteuerung auf dem Slave-ESP32 wurde ¨ mittels vier dedizierten C++-Dateien, einer zentralen Ino-Datei und fünf Header-Dateien umgesetzt. Die Auflistung der einzelnen Dateien sowie ihre Funktion ist in Tabelle 6 zu finden.

Die Erzeugung der periodischen Spannungssignale wird durch den Mikrocontroller übernommen,
indem dieser in regelmaßigen Abst ¨ | anden vorberechnete Stützwerte über die zwei internen 8-Bit- ¨
DAC-Kanale ausgibt. Die Generierung der Signalwerte erfolgt vollst ¨ | andig durch den Programm- ¨
code des Mikrocontrollers, wahrend der DAC ausschließlich die Funktion eines spannungsausge- ¨ benden Endglieds übernimmt.

Die internen DACs des ESP32 sind nach dem Prinzip des sogenannten R-String-DAC aufgebaut. Eine Reihenschaltung von 256 gleich großen Widerstanden liegt zwischen der Referenzspan- ¨ nung Vr e f und Masse und bildet einen Spannungsteiler mit 256 Abgriffen. Ein digital gesteuertes Multiplexer-Netzwerk wahlt anhand des 8-Bit-Eingangswortes den entsprechenden Abgriff aus, ¨ dessen Spannung anschließend durch einen integrierten Verstarker niederohmig am Ausgangspin ¨
bereitgestellt wird. Beide DAC-Kanale arbeiten unabh ¨ | angig voneinander und k ¨ | onnen simultan ¨
mit unterschiedlichen Werten beschrieben werden. Als Referenzspannung dient die Versorgungsspannung VDD3P3 RTC, die im Datenblatt mit 3,3 V angegeben ist. [20, S. 745-746] [21, S. 70]

Die am Ausgang anliegende Spannung berechnet sich für jeden Kanal nach Formel 3, wobei Vr e f die Referenzspannung und digiV alue den geschriebenen digitalen Wert im Bereich von 0 bis 255 bezeichnet. [22]

Tabelle 6: Ubersicht der Dateien für die Ansteuerung der Komponenten und Ausgabe der Span- ¨ nungen des Slave-ESP32

Dateiname | Funktion
ESP32DevMod.ino | Hauptdatei. Verantwortlich für die Verknüpfung
der einzelnen Unterdateien und das Ausführen
| der Funktionen.
dac output.cpp und dac output.h | Dateien für die Steuerung der
Spannungsausgabe über die internen DAC-Pins, falls diese über das HMI gestartet oder gestoppt wird.
ws2812b.cpp und ws2812b.h | Dateien für die Ansteuerung des adressierbaren
| LED-Streifens.
save data.cpp und save data.h | Dateien für das Speichern der Gruppenparameter im NVS.
signal config.h | Datei für die Definition der Signalkonfiguration
| der UART-Ubertragung. ¨
uart.cpp und uart.h | Dateien für die Umsetzung der
UART-Kommunikation zwischen dem HMI (Master) und dem ESP32 DevKit (Slave).

VOut =

Vr e f · digiV alue
255 | (3)

Aus dieser Beziehung ergibt sich die kleinste auflosbare Spannungsstufe nach Formel 4. ¨

Vste p =

Vr e f
2

n − 1

=

3,3 V
255 ≈ 12,9 mV | (4)
Eine messtechnische Uberprüfung der tats ¨ | achlichen Ausgangsspannung am DAC-Pin zeigte je- ¨

doch, dass die realen Spannungswerte von dieser theoretischen Berechnung abweichen. Bei einem Eingangswort von 0 wurde am Oszilloskop eine Restspannung von etwa 0,1 V gemessen. Bei einem Eingangswort von 255 erreichte die Ausgangsspannung lediglich 3,127 V anstelle der erwarteten 3,3 V. Um die Signalgenerierung ausschließlich im linearen Bereich des DAC durchzuführen, wurde der nutzbare Spannungsbereich softwareseitig auf 0 V bis 3 V begrenzt.

Da der DAC für einen gegebenen Eingangswert lediglich eine statische Spannung ausgibt, muss der Mikrocontroller die zur jeweiligen Signalform gehorenden Werte fortlaufend berechnen und ¨ in den DAC schreiben. Hierfür wurde auf dem Slave ein softwarebasierter numerischer Oszillator nach dem Phaseninkrement-Verfahren implementiert. Dieser greift auf dasselbe Grundprinzip, das auch der in Kapitel 6 beschriebenen DDS zugrunde liegt, zurück, führt die Berechnung jedoch vollstandig im Programmcode auf dem ESP32 durch. ¨

Für jeden Kanal wird hierzu eine Phasenvariable φacc eingeführt, die in jedem Durchlauf der Hauptschleife um ein Phaseninkrement entsprechend der vergangenen Zeit Δt und der gewünschten Frequenz f erhoht wird. Formel 5 zeigt die Berechnung der Phasenvariable. ¨

φacc [n] = φacc [n − 1] + 2π · f · Δt | (5)

Die Zeitdifferenz Δt wird über die Funktion micros() zwischen zwei Schleifendurchlaufen ¨ bestimmt, sodass keine fest definierte Sample-Rate erforderlich ist. Sobald φacc den Wert 2π überschreitet, wird der Wert der Phasenvariable um eine volle Periode reduziert, damit diese
nicht unbegrenzt wachst. Anschließend wird der momentane Signalwert in Abh ¨ | angigkeit der ¨
ausgewahlten Signalform berechnet. Sinusf ¨ | ormige Signale entstehen durch die Auswertung von ¨
sin(φacc) über die C-Standardfunktion sinf(), wahrend rechteckf ¨ | ormige Signale durch die Aus- ¨
wertung des Vorzeichens des Sinus erzeugt werden. Diese Losung kommt ohne eine separate ¨ Tabellenstruktur aus, wie sie etwa bei DDS-ICs verwendet wird. Dies geht jedoch zu Lasten der erreichbaren Ausgangsfrequenz, da pro Abtastwert eine vollstandige Gleitkommarechnung durch- ¨ geführt werden muss.

Die in Anforderung FA-5 geforderte Phasenverschiebung zwischen den beiden Kanalen wird durch ¨ eine unterschiedliche Initialisierung der jeweiligen Phasenvariable realisiert. Beim Start einer Gruppe werden φacc,1, sowie φacc,2 mit den in Grad vorgegebenen und in Radiant umgerechneten Phasenwerten initialisiert. Das Vorzeichen des Phasenwertes wird dabei invertiert, sodass ein positiver Vorgabewert einer Nacheilung des betreffenden Kanals entspricht. Anschließend wird die
Zeitbasis für beide Kanale neu gesetzt, sodass beide Kan ¨ | ale synchron starten und der vorgegebene ¨

Phasenversatz exakt eingehalten wird.

Der interne DAC kann ausschließlich positive Spannung im Bereich von 0 V bis 3 V (nach durchgeführter Kalibrierung) ausgeben. Der Laborversuch benotigt jedoch um den Nullpunkt ¨ symmetrische Signale. Um dies zu erreichen, wird der Mittelwert des Aussteuerungsbereichs als virtueller Nullpunkt definiert. Da der DAC den ganzzahligen Wertebereich von 0 bis 255 abbildet, liegt dieser rechnerische Mittelwert bei 127,5. Alle Signalwerte schwingen symmetrisch um diesen Mittelwert, sodass am DAC-Pin ein Wechselspannungssignal anliegt, das mit einem Gleichspannungsoffset von etwa 1,5 V überlagert ist. Ein in Reihe liegender Kondensator blockiert den Gleichspannungsanteil und gibt nur den Wechselspannungsanteil an den Ausgang weiter. Damit steht eine nutzbare Amplitude von ±1, 5 V um den Nullpunkt am Ausgang des Funktionsgenerators zur Verfügung. Die Umrechnung der gewünschten Amplitude in DAC-Schritte erfolgt nach Formel 6 mit Vmax = 1, 5 V.

counts =

Vsoll

Vmax

- 127, 5 | (6)

Amplituden, die diesen Wert überschreiten, werden auf den maximalen Hub begrenzt. Der schließlich an den DAC übergebene digitale Wert berechnet sich nach Formel 7:

digiV alue = round
127,5 + counts · wave(φacc)
(7)

Der Term wave(φacc) liefert den momentanen Wert der Wellenform im Bereich von −1 bis +1 und entspricht, je nach gewahlter Signalform, entweder dem Sinuswert selbst oder dessen Vorzeichen. ¨ Da der DAC ausschließlich ganzzahlige Eingangswerte verarbeiten kann, wird der intern berechnete
Wert vor der Ubergabe an die Funktion ¨ | dacWrite() durch die Funktion roundf() auf die nachste ¨
ganze Zahl gerundet. Eine zusatzliche Begrenzung mittels ¨ | constrain() auf den Bereich von 0 bis
255 stellt sicher, dass auch bei Rundungsfehlern an den Randern des Aussteuerungsbereichs keine ¨ ungültigen Werte an den DAC übergeben werden. Die vollstandige Funktion zur DAC-Ausgabe ist ¨ in Listing 3 auf Seite 61 im Anhang dargestellt.
Im Stopp-Zustand werden beide DAC-Kanale auf den n ¨ | achstliegenden ganzzahligen Mittelwert ¨
128 zurückgesetzt, sodass nach dem in Reihe liegenden Kondensator eine Ausgangsspannung von 0 V anliegt. Abbildungen 14 und 15 auf den Seiten 62 und 63 im Anhang zeigen exemplarisch die beiden Ausgangssignale bei unterschiedlichen Ausgangsfrequenzen.

Die hier beschriebene Kalibrierung beschrankt sich somit auf die softwareseitige Anpassung des ¨ nutzbaren Aussteuerungsbereichs auf den linearen Arbeitsbereich des DACs. Eine darüber hinausgehende messtechnische Bewertung der erzielten Signalqualitat, insbesondere der verbleibenden ¨ Amplituden- und Frequenzabweichungen, erfolgt im Rahmen des Abschnitts 5.4.

### 5.4. Messaufbau, Testversuche und Genauigkeitsbewertung

Zur Bewertung der in Abschnitt 5.3 beschriebenen Signalerzeugung wurde eine systematische Messreihe durchgeführt. Ziel dieser Messung ist die Uberprüfung der in Abschnitt 3.3 aufgelisteten ¨

nicht-funktionalen Anforderungen. Insbesondere liegt der Fokus auf den ersten drei NFA sowie die Identifizierung moglicher Abweichungen und deren Ursachen. Die Ergebnisse bilden zugleich ¨ die Datenbasis für den spateren Vergleich der beiden Implementierungsmethoden in Kapitel 9. ¨

Für die Erfassung der Ausgangssignale wurde ein Keysight InfiniiVision 2000 X-Series Oszilloskop verwendet, wie es auch in den Laborraumen der HWR Berlin für die in Abschnitt 3.1 ¨ beschriebenen Versuche eingesetzt wird. Damit erfolgt die Validierung des Funktionsgenerators
unter den spateren Einsatzbedingungen. Die relevanten Spezifikationen des Messger ¨ | ats sind in ¨
Tabelle 7 zusammengefasst.

Tabelle 7: Spezifikationen des verwendeten Oszilloskops (Keysight InfiniiVision 2000 X-Series) [23, S. 4-5]

Parameter | Wert
Bandbreite | 70 MHz
Abtastrate (interleaved) | 2 GSa/s
Abtastrate (pro Kanal) | 1 GSa/s
Anzahl analoger Kanale | 2 ¨
Vertikale Auflosung | 8 bit ¨

Die Bandbreite und Abtastrate des Oszilloskops liegen mehrere Großenordnungen über den vom ¨ Funktionsgenerator erzeugten Signalen. Eine Beeintrachtigung der Messgenauigkeit durch das ¨ Oszilloskop ist daher sehr gering [23, S. 5].

Die Messreihe wurde so konzipiert, dass alle drei zu prüfenden nicht-funktionalen Anforderungen (Amplituden-, Frequenz- und Phasengenauigkeit) systematisch erfasst werden. Hierzu wurden die getesteten Signalformen (Sinus und Rechteck) für mehrere Ausgangsfrequenzen von 1 Hz bis 10 kHz untersucht. Innerhalb jeder Frequenzstufe wurde die Soll-Amplitude in Schritten von 100 mV bis 1500 mV variiert. Die Soll-Phase zwischen Kanal 1 und Kanal 2 betrug bei allen Messungen 90°. Die einzelnen Parametersatze wurden nacheinander ausgegeben. Zur Erfassung ¨

der Ist-Werte wurden die Messwerte mithilfe der automatischen Messfunktion des Oszilloskops unter Verwendung der DC-Kopplung ausgelesen.

Insgesamt wurden auf diese Weise 150 Messpunkte erfasst. Für jede der getesteten Frequenzstufen wurden 15 Amplitudenstufen, sowohl für ein sinus- als auch für ein rechteckformiges Signal, ¨ aufgenommen. Die ausgelesenen Ist-Werte wurden gemeinsam mit den zugehorigen Soll-Werten ¨ tabellarisch erfasst und bilden die Grundlage der nachfolgenden Auswertung. Zur Bewertung der einzelnen Anforderungen wird im Folgenden jeweils der relative Fehler zwischen Soll- und Ist-Wert betrachtet.

Amplitudengenauigkeit (NFA-1):

Die Amplitudenmessung wurde mittels der Top-Messung durchgeführt. Im Anhang auf den Seiten 64 und 65 zeigen die Abbildungen 16 und 17 den relativen Amplitudenfehler in Abhangigkeit ¨ der eingestellten Soll-Amplitude, getrennt nach sinus- und rechteckformigem Signal. Für beide ¨ Signalformen wird anhand der Messdaten ein klarer Trend erkennbar.

Mit zunehmender Soll-Amplitude sinkt der relative Fehler deutlich ab. Beim Sinussignal ist zu erkennen, dass die relative Abweichung bei niedrigen Amplituden bis zu rund 80 % betragen kann. Sowohl im Mittel als auch im Median liegen die Messwerte bei einer Soll-Amplitude von 100 mV etwa 79 % oberhalb des vorgegebenen Wertes. Dies stellt eine erhebliche Verletzung der Anforderung NFA-1 dar, weshalb dieser Bereich für den Anwendungsfall ausscheidet.

Ab einer Soll-Amplitude von 200 mV weichen Mittel- und Medianwert deutlich voneinander ab. Wahrend die mittlere Abweichung bei 200 mV und 300 mV mit rund 7 % bis 8 % oberhalb ¨ des Toleranzbereichs liegt, betragt die mediane Abweichung lediglich etwa 1,5 % bzw. 2,7 % ¨ und liegt damit innerhalb der Toleranz. Diese Differenz entsteht dadurch, dass der Mittelwert durch einzelne Ausreißer nach oben verzerrt wird, wahrend der Median als robustes Lagemaß von ¨ solchen Einzelwerten nahezu unbeeinflusst bleibt. Verantwortlich für diese Ausreißer sind in erster Linie die Messwerte bei der Ausgangsfrequenz von 1 Hz, deren Signalfrequenz im Bereich der
Grenzfrequenz des Koppelkondensators liegt und die daher nur eingeschrankt zuverl ¨ | assig erfasst ¨
werden konnten.

Uber den gesamten Bereich ab 200 mV liegt die mediane Abweichung jeder Amplitudenstufe ¨

innerhalb der geforderten ±5 %-Toleranz und erreicht einen maximalen Wert von rund 4,4 % bei einer Soll-Amplitude von 500 mV. Das typische Messverhalten erfüllt die Anforderung NFA-1
in diesem Bereich somit zuverlassig, und die nach Mittelwert auftretenden ¨ | Uberschreitungen bei ¨

200 mV, 300 mV und 500 mV beschranken sich auf einzelne Ausreißer. ¨

Beim Rechtecksignal fallt der relative Fehler über den gesamten Amplitudenbereich deutlich ¨ geringer aus. Selbst bei der kleinsten Soll-Amplitude von 100 mV betragt die mittlere Abweichung ¨ lediglich rund 5 % (maximal etwa 9 %). Der Median liegt hier mit rund 4 % bereits innerhalb der Toleranz, ohne den beim Sinus beobachteten starken Ausreißer aufzuweisen. Uber den übrigen ¨

Amplitudenbereich bewegen sich die medianen Abweichungen durchgehend zwischen etwa 2,7 %
und 4,6 % und damit vollstandig innerhalb der Toleranz, w ¨ | ahrend die Mittelwerte vereinzelt knapp ¨
darüber liegen.

Dieses unterschiedliche Verhalten der beiden Signalformen lasst sich wahrscheinlich auf die Art ¨
der Signalerzeugung zurückführen. Wahrend das sinusf ¨ | ormige Signal treppenf ¨ | ormig aus einer ¨
Vielzahl von DAC-Stufen zusammengesetzt wird, nutzt das Rechtecksignal lediglich zwei feste Pegel, den oberen und den unteren DAC-Wert. Die Amplitude ergibt sich somit unmittelbar aus der Differenz dieser beiden Pegel und wird auch bei kleinen Amplituden zuverlassig erfasst. ¨
Insgesamt liegen 71 der 90 sinusformigen und 50 der 60 rechteckf ¨ | ormigen Messpunkte innerhalb ¨
der geforderten Toleranz von ±5 %. Die Anforderung NFA-1 wird damit über weite Teile des nutzbaren Aussteuerungsbereichs erfüllt. Im Bereich sehr kleiner Amplituden, insbesondere bei
Vout | ≤100 mV im Sinusbetrieb, jedoch deutlich verletzt. Da die den einzelnen Arbeitsgruppen
zugewiesenen Amplitudenwerte gemaß NFA-5 frei festgelegt werden k ¨ | onnen, l ¨ | asst sich dieser ¨
kritische Bereich im praktischen Einsatz umgehen. Für den vorgesehenen Anwendungsfall kann die Anforderung NFA-1 daher als erfüllbar betrachtet werden, wobei die eingeschrankte Genauigkeit ¨ bei kleinen Amplituden als bauteilbedingte Limitierung der DAC-basierten Methode festzuhalten ist.

Phasengenauigkeit (NFA-2):

Abbildung 18 auf Seite 66 im Anhang zeigt die absolute Phasenabweichung von der vorgegebenen Phasenverschiebung von 90° in Abhangigkeit der Ausgangsspannung und Frequenz. Der ¨

Phasenfehler zeigt keinen ausgepragten Zusammenhang mit der eingestellten Amplitude, sondern ¨ variiert in erster Linie mit der Frequenz. Die geforderte Toleranz von ±2° wird nur in einem mittle-

ren Frequenzbereich zuverlassig eingehalten, w ¨ | ahrend die Abweichungen zu niedrigen und hohen ¨
Frequenzen hin zunehmen.

Beim Rechtecksignal sind die Ergebnisse im unteren Frequenzbereich am besten. Bei 10 Hz und 100 Hz liegen alle Messpunkte innerhalb der Toleranz (max. 0,12° bzw. 0,63°). Mit steigender Frequenz nimmt der Fehler deutlich zu. Bei 500 Hz steigt der Fehler auf rund 4° (8 von 15 Punkten konform), bei 1 kHz auf etwa 9,5° (nur 2 von 15 Punkten konform).

Beim Sinussignal wird die geringste Abweichung im mittleren Frequenzbereich erreicht. Bei 100 Hz liegen 13 von 15 Messpunkten innerhalb der Toleranz (max. 2,43°). Zu niedrigen Frequenzen hin steigt der Fehler auf bis zu 6,47° (10 Hz) und 8,75° (1 Hz). Bei hoheren Frequenzen von 500 Hz, ¨ 1 kHz und 2 kHz liegt der Fehler bei bis zu 4,87°, 3,74° bzw. 4,61°.

Zusatzlich w ¨ | achst die Phasenabweichung im Dauerbetrieb langsam an, wodurch nach mehr als ¨
10 Minuten eine signifikante Abweichung entsteht. Ursache dafür ist die fortlaufende numerische Akkumulation der Phasenwerte. Eine Korrektur durch periodisches Zurücksetzen beider Phasenwerte auf den Sollwert ware m ¨ oglich, würde jedoch einen kurzen Aussetzer im Signalverlauf des ¨ Oszilloskops verursachen. Somit gilt die FA-5 nur als teilweise erfüllt.

Insgesamt erfüllen 50 der 90 sinus- und 40 der 60 rechteckformigen Messpunkte die Anforderung ¨ NFA-2. Die geforderte Phasengenauigkeit von ±2° kann durch die DAC-basierte Methode somit

nicht über den gesamten Parameterbereich, sondern nur innerhalb eines mittleren Frequenzbandes sichergestellt werden. Dies schrankt den Einstellbereich für die Phasenverschiebung ein. Innerhalb ¨ dieses eingeschrankten Bereichs wird die NFA-2 jedoch erfüllt. ¨

Frequenzgenauigkeit (NFA-3):

Die Frequenzgenauigkeit der DAC-Kanale erweist sich als sehr hoch und stabil. Die maximale ¨ prozentuale Abweichung liegt beim Sinussignal bei ca. 2,3 % und beim Rechtecksignal bei gerade einmal 0,84 %. Die geforderte Toleranz von ±5 % wurde damit von allen Messwerten vollstandig ¨ eingehalten. Abbildung 19 auf Seite 67 im Anhang stellt die Messergebnisse dar. Die Anforderung NFA-3 ist somit vollumfanglich erfüllt. ¨

Anzumerken ist, dass die rechteckformigen Signale nicht über denselben Frequenzbereich wie die ¨ sinusformigen Signale vermessen werden konnten. Bei einer Frequenz von 1 Hz wies das Aus- ¨ gangssignal zu Beginn jeder Halbperiode deutlich überhohte Spannungswerte auf und flachte an- ¨ schließend über die Halbperiode hinweg merklich ab, sodass am Oszilloskop kein rechteckformiger ¨ Signalverlauf, sondern eher abklingende Spitzen zu erkennen waren. Abbildung 20 auf der Seite 68 im Anhang stellt genau dieses Spannungssignal dar. Eine zuverlassige Erfassung von Amplitude ¨ und Phase war unter diesen Bedingungen nicht moglich. Vermutlich ist dieses Verhalten auf den in ¨ Abschnitt 5.2 beschriebenen Koppelkondensator zurückzuführen, dessen Grenzfrequenz mit rund 1,59 Hz im Bereich der Signalfrequenz liegt. Aus diesem Grund wurde für das Rechtecksignal auf eine Messung bei 1 Hz verzichtet.

Oberhalb von etwa 1 kHz konnte die Phasenverschiebung des Rechtecksignals ebenfalls nicht mehr sinnvoll abgelesen werden. Die Darstellung am Oszilloskop war in diesem Bereich nicht mehr stabil, sondern sprang fortlaufend hin und her, sodass weder die Phase noch die Amplitude zuverlassig bestimmt werden konnten. ¨

Die Messreihe des rechteckformigen Signals beschr ¨ | ankt sich daher auf den Bereich von 10 Hz bis ¨
1 kHz. Beim sinusformigen Signal trat ab einer Frequenz von etwa 2 kHz eine zunehmend trep- ¨ penformige Verzerrung des Signalverlaufs auf. Da die Stützwerte des Signals fortlaufend durch den ¨ Programmcode berechnet und an den DAC übergeben werden, nimmt die Anzahl der pro Periode ausgegebenen Stützwerte mit steigender Frequenz ab. Es liegt daher nahe, dass die zunehmende Treppenform auf die begrenzte Anzahl an Stützwerten pro Periode in diesem Frequenzbereich zurückzuführen ist. Abbildung 14b auf Seite 62 im Anhang zeigt den stufenformigen Signalverlauf ¨ bei einer Frequenz von 2 kHz.

Reaktionstest (NFA-6):

Zur Validierung der Anforderung NFA-6 wurde mit Hilfe eines Logic Analyzers ein Reaktionstest durchgeführt. Der zugehorige Messaufbau ist in Abbildung 21 auf Seite 69 im Anhang dargestellt. ¨ Für die Messung wurde ein dedizierter GPIO-Pin des Masters verwendet, der auf High gesetzt wird, sobald das Display eine Berührung erkennt. Dieser Trigger-Pin, das DAC-Ausgangssignal sowie die beiden UART-Leitungen wurden an die Kanale des Logic Analyzers angeschlossen. ¨ Die Zeitdifferenz zwischen der steigenden Flanke des Trigger-Pins und der daraus resultierenden Parameteranderung am DAC-Ausgang entspricht der internen Reaktionszeit des Systems. Die ¨ Ausgabe wurde Softwareseitig so angepasst, dass der DAC-Ausgang ein konstantes 1 V Signal auf Kanal 1 ausgibt.

Die Touch-Polling-Rate des Displays ist in der Konfigurationsdatei lv conf.h (Zeile 83) auf 30 ms vordefiniert. Das Display prüft somit alle 30 ms, ob ein Touch-Ereignis aufgetreten ist. Zur Bestimmung der Reaktionszeit wird daher vom ungünstigsten Fall ausgegangen, bei dem die Berührung unmittelbar nach einem Abfragezyklus erfolgt und somit eine zusatzliche Latenz von ¨
30 ms entsteht. Diese Polling-Rate ließe sich grundsatzlich erh ¨ | ohen, um die Reaktionszeit weiter ¨
zu senken, allerdings zulasten der verfügbaren CPU-Leistung.

Tabelle 8 fasst die Ergebnisse von fünf Einzelmessungen zusammen. Die am Logic Analyzer gemessene Verarbeitungs- und Ausgabezeit (tAusgang) liegt in allen Fallen unter 2,1 ms. Zusammen ¨ mit der Worst-Case-Polling-Latenz von 30 ms (tTouch) ergibt sich eine maximale Reaktionszeit von

Tabelle 8: Reaktionszeitmessung zur Uberprüfung der Anforderung NFA-6 (DAC) ¨

Messung | tTouch [ms] | tAusgang [ms] | Reaktionszeit [ms] | NFA-6 erfullt? ( ¨ | Δt < 100 ms)
1 | 30 | 2,05 | 32,05 | Ja
2 | 30 | 1,70 | 31,70 | Ja
3 | 30 | 1,75 | 31,75 | Ja
4 | 30 | 1,86 | 31,86 | Ja
5 | 30 | 1,73 | 31,73 | Ja

rund 32 ms. Die geforderte Obergrenze von 100 ms wird damit deutlich unterschritten, sodass die Anforderung NFA-6 erfüllt ist. Abbildung 22 auf der Seite 70 im Anhang zeigt die Auswertung vom Logic Analyzer für einen der Reaktionstests.

### 6. Implementierungsmethode B: Signalgenerierung mittels Direct Digital Synthesis

### 6.1. Konzept und Komponentenauswahl

Wie in Kapitel 2.3 bereits angemerkt, gibt es heutzutage grundsatzlich zwei etablierte M ¨ | oglichkeiten, ¨
die für die Generierung von Spannungssignalen genutzt werden. Neben der in Kapitel 5 beschriebenen Variante mittels interner Digital-Analog-Wandler gibt es zudem die Moglichkeit, die Signalge- ¨ nerierung über Direct Digital Synthesis, beispielsweise über einen externen DDS-IC, umzusetzen. Wie bereits erwahnt, erfolgen bei der DDS die Signalgenerierung und die Digital-Analog-Wandlung ¨ meist in einem einzelnen dedizierten Baustein. Ist dies der Fall, spricht man von einem sogenannten vollstandigen DDS-Modul. [11, S. 2] Der Grundaufbau eines DDS-Moduls besteht aus einem ¨ Phasenakkumulator, einer Moglichkeit, die Phasenvorgabe in eine Amplitude umzuwandeln und ¨ einem Digital-Analog-Wandler. [11, S. 1] Dieser Aufbau ist in Abbildung 6 dargestellt.

Ein DDS-Modul erzeugt ein Sinussignal mit einer bestimmten Frequenz. Die Frequenz ist dabei von zwei Parametern, der Frequenz der reference-clock und dem in Punkt 2.3 bereits erwahnten ¨ tuning-word, abhangig. Der Phasenakkumulator erzeugt bestimmte Phasenwerte, die als Adressen ¨ für eine Sinus-Lookup-Tabelle verwendet werden. Die Tabelle liefert zu jedem Phasenwert den entsprechenden digitalen Amplitudenwert eines Sinussignals, welcher anschließend durch einen DAC in eine analoge Spannung oder einen Strom umgewandelt wird. Die Ausgangsfrequenz des Signals wird durch das Phaseninkrement, welches wiederum durch das tuning-word bestimmt wird, festgelegt. Große Inkremente erzeugen dabei hohe und kleine Inkremente niedrige Frequenzen. [11, S. 1] Der Phasenakkumulator agiert innerhalb eines DDS-Moduls als Phasenkreis mit mehreren festgelegten Punkten (Abbildung 7). Jeder dieser definierten Punkte entspricht dabei einem bestimmten Punkt einer Sinusperiode. Wahrend sich ein Vektor mit konstanter Geschwindigkeit ¨ um den Kreis bewegt, erzeugt der Sinus des jeweiligen Winkels des Vektors das entsprechende Aus-
gangssignal. Eine vollstandige Umdrehung des Vektors entspricht dabei genau einer vollst ¨ | andigen ¨
Periode der Sinuswelle. Das tuning-word legt dabei die Schrittweite M auf dem Phasenkreis fest. Große Schrittweiten führen dazu, dass der Phasenakkumulator schneller überlauft und somit ¨
hohere Ausgangsfrequenzen erzeugt werden. Die Anzahl der m ¨ | oglichen Phasenpunkte wird durch ¨
die Auflosung des Phasenakkumulators ¨ | n bestimmt und beeinflusst direkt die Frequenzauflosung ¨
des DDS-Systems. [11, S. 2]

Für die Umsetzung dieses Projekts wurde ein DDS-Modul auf Grundlage des programmierbaren

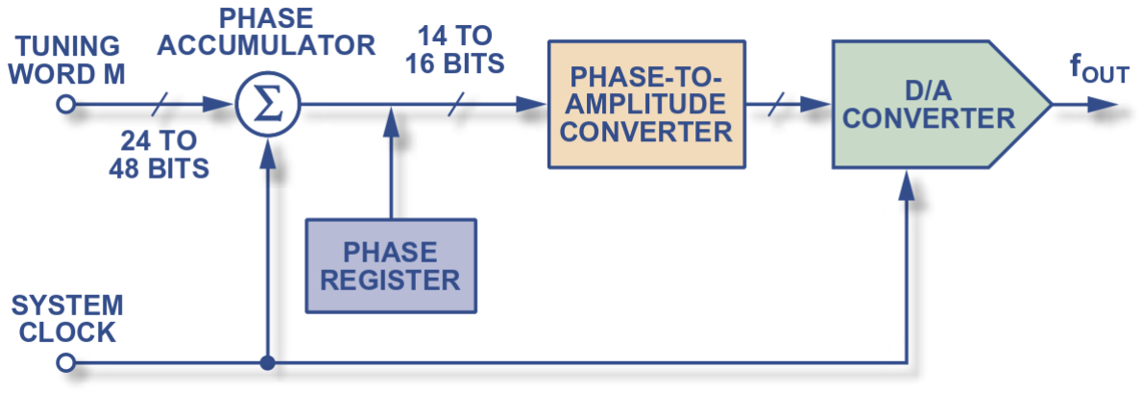
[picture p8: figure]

Abbildung 6: Bestandteile eines Direct Digital Synthesisers [11, S. 1]

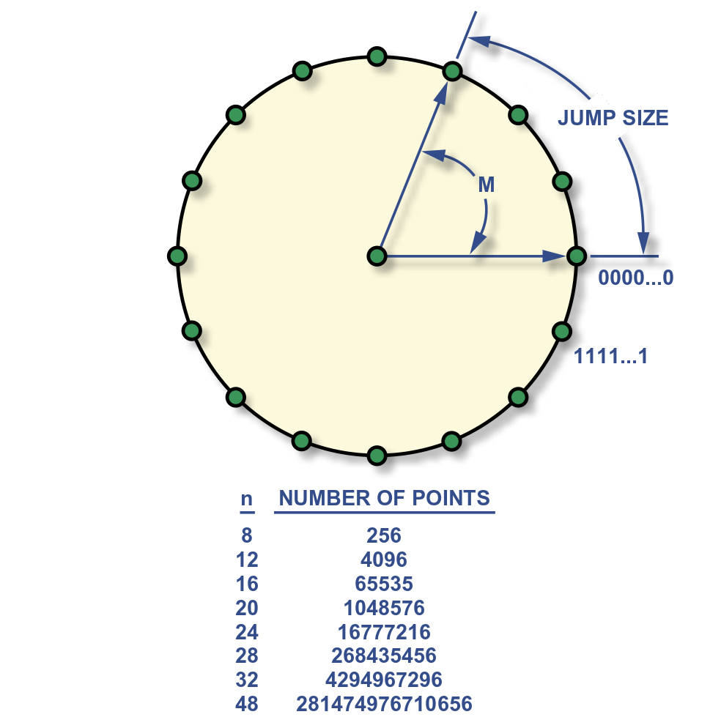
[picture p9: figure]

Abbildung 7: Digitaler Phasenkreis eines DDS-ICs [11, S. 2]

Wellenformgenerators AD9833 der Firma Analog Devices ausgewahlt. Der AD9833 ist ein weit- ¨ verbreiteter und kostengünstiger DDS-IC mit einer Ausgangsfrequenz von 0 bis 12,5 MHz und einer Auflosung von 28-Bit. [26, S. 1] Angesteuert wird der IC mittels einer 3-Draht-Schnittstelle über ¨ SPI, QSPI, MICROWIRE oder DSP. [26, S. 13] Das verwendete AD9833-Modul ist in Abbildung 8 zu sehen.

Der AD9833 eignet sich sowohl für die Generierung von sinus- als auch rechteckformigen Span- ¨ nungssignalen, wie unter FA-2 gefordert. Ausgestattet ist der IC mit zwei 28-Bit-Frequenzregistern (FREQ0 und FREQ1), zwei 16-Bit-Phasenregistern (PHASE0 und PHASE1) sowie einem 10-Bit-DAC, über welchen das analoge Spannungssignal ausgegeben wird. [26, S. 1] Ein funktionales Blockdiagramm des Aufbaus ist in Abbildung 23 auf der Seite 71 im Anhang zu finden. Insgesamt besitzt der AD9833 10 Pins, von denen jedoch nur sieben über die Anschlüsse des Moduls zur Verfügung stehen. Die Pins sowie die ihnen zugewiesenen Funktionen sind in Tabelle 9 aufgelistet.

Identisch zur obigen Beschreibung der Funktionsweise eines DDS-Moduls verwendet der AD9833 das im Frequenzregister gespeicherte Frequenzwort sowie den Takt des auf dem Modul vorhandenen 25 MHz Quarz, um die Ausgangsfrequenz des Spannungssignals zu verandern. ¨

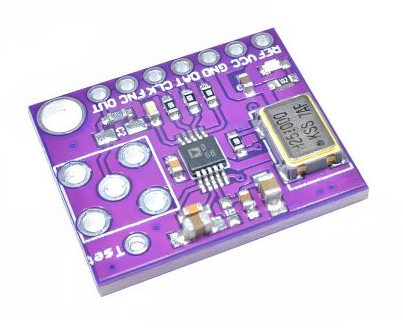
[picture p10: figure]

Abbildung 8: AD9833-Modul mit integriertem 25 MHz Quarz [27]

Berechnet wird die Ausgangsfrequenz dabei durch die Formel:

fMCLK
2
28 | · FREQREG | (8)

Dabei stehen fMCLK für die Taktfrequenz des Quarzes und FREQREG für den im ausgewahlten ¨ Frequenzregister gespeicherten Wert. Dieses Signal wird um eine bestimmte Phase, die sich aus der nachfolgenden Gleichung berechnet, verschoben.

2 · π
4096
- PH ASE REG | (9)

PH ASE REG steht dabei für den Wert, der im ausgewahlten Phasenregister gespeichert ist. [26, ¨
S. 15] Insgesamt besitzt der IC 15 Kontrollbits, welche unter anderem für die Auswahl der Datenregister, das Zurücksetzen des ICs, das Aktivieren des Sleep-Modus und das Umschalten des Ausgangssignals verwendet werden. Für die Auswahl der Frequenzregister werden Bit 15 und Bit 14 verwendet [(01)2 steht dabei für FREQ0 und (10)2 für FREQ1]. Für die Auswahl des Phasenregisters sind Bit 15, Bit 14 und Bit 13 verantwortlich [(110)2 steht dabei für PHASE0 und (111)2 für PHASE1). Ist der FSYNC-Pin Low und entspricht Bit 13 dem Wert Eins, konnen die Daten in die ¨ Register getaktet werden. [26, S. 13-15] Für das Umschalten zwischen sinus- und rechteckformiger ¨ Ausgangsspannung werden Bit 5, Bit 3 und Bit 1 verwendet. Durch den Zustand (0X0)2, wobei X
für einen beliebigen Wert steht, wird ein sinusformiges Signal ausgegeben. Durch (110) ¨ | 2 wird das
Most Significant Bit (MSB) des DACs, was einem Rechtecksignal entspricht, am Ausgang ausge-

Tabelle 9: Pinbeschreibung des AD9833-Moduls [26, S. 6]

Pin | Verwendung
OUT | Spannungsausgang. An diesem Pin steht der
analoge bzw. digitale Ausgang des AD9833 zur Verfügung.
GND | Masse
FSYNC | FSYNC dient als Synchronisationssignal für die
Eingangsdaten. Wird FSYNC auf Low gesetzt, erkennt die interne Logik, dass ein neues Datenwort in das Gerat geladen werden soll. ¨
SCLK | Serieller Takteingang. Die Daten werden mit
jeder fallenden Flanke von SCLK in den AD9833 eingetaktet.
SDATA | Serieller Dateineingang. Uber diesen Eingang ¨
wird das 16-Bit-Datenwort an den AD9833 übertragen.
REF | Uber diesen Pin kann das Taktsignal der ¨
reference-clock, welches am MCLK-Pin anliegt, abgegriffen werden.
VCC | Positive Versorgungsspannung.

geben. Durch Bit 7 und Bit 6 kann der Chip in einen Sleep-Modus versetzt werden. [26, S. 16] Der
IC ermoglicht es jedoch nicht, die Ausgangsspannung über die Kontrollbits zu ver ¨ | andern. Laut ¨
Datenblatt liefert der AD9833 bei der Ausgabe eines sinusformigen Signals 0,65 V als maximale ¨ und 38 mV als minimale Ausgangsspannung. [26, S. 3] Da bei der Rechteckausgabe das MSB des DACs ausgegeben wird, entspricht die Ausgangsspannung ca. der Versorgungsspannung (2,3 V
bis 5,5 V). [26, S. 1] Dabei ist zu erwahnen, dass die Ausgangsspannung neben dem ausgew ¨ | ahlten ¨
Modus ebenfalls von der Frequenz des Ausgangssignals abhangt. Die Ausgangsspannung des ¨
AD9833 in Abhangigkeit der Ausgangsfrequenz und des ausgew ¨ | ahlten Modus ist in Abbildung ¨
24 auf Seite 72 im Anhang zu sehen. Zudem kann für die Umsetzung des Projektes nicht der vollstandige Frequenzbereich des ICs verwendet werden, da die Verzerrung des Ausgangssignals ¨ mit zunehmender Ausgangsfrequenz immer weiter zunimmt. Dies ist in Abbildung 25 auf Seite 73 im Anhang zu sehen. Dadurch sinkt die maximale Ausgangsfrequenz auf ca. 1 MHz, da bei
dieser Frequenz sowohl das sinusformige als auch das rechteckf ¨ | ormige Spannungssignal weitest- ¨
gehend unverzerrt bleiben. Dies würde weiterhin die unter NFA-4 gestellten Anforderungen an den einstellbaren Frequenzbereich erfüllen.

Um einen für den Laborversuch gemaß NFA-5 geeigneten Spannungsbereich bereitzustellen, ¨ müssen in beiden Betriebsvarianten identische Spannungswerte erreicht werden. Zudem soll der verwendete Slave eine flexible Anpassung der Ausgangsspannung ermoglichen. Um sowohl im ¨ Sinus- als auch im Rechteckbetrieb eine identische Ausgangsspannung zu erreichen, wird eine
Verstarkerschaltung mittels eines Operationsverst ¨ | arkers (OPV) verwendet. Dieser kann die Si- ¨
gnale auf einen identischen und gleichzeitig besser nutzbaren Spannungswert verstarken. Um ¨
die Ausgangsspannung der Verstarkerschaltung anpassen zu k ¨ | onnen, wird die Eingangsspannung ¨
des OPVs über einen Spannungsteiler verandert. Um das Verh ¨ | altnis des Spannungsteilers durch ¨
den Programmcode steuern zu konnen, wurden digitale Potentiometer, welche über eine serielle ¨ Schnittstelle angesteuert werden, verwendet.

Zu Beginn des Entwicklungsprozesses fiel die Entscheidung zunachst auf die digitalen Potentiome- ¨ ter DS1803-100 der Firma Analog Devices. Diese wurden jedoch im weiteren Entwicklungsprozess durch Potentiometer des Typs MCP42010 der Firma Microchip Technology ersetzt. Warum diese Entscheidung getroffen wurde, wird in den nachfolgenden Abschnitten erklart. Grundlegend han- ¨ delt es sich bei beiden ICs um kostengünstige und leicht verfügbare digitale Potentiometer mit 256 moglichen Einstellpositionen, von denen jeweils zwei pro IC verbaut sind (Pot-0 und Pot-1). [28, ¨
S. 1] [29, S. 1]

Unterschiede weisen sie jedoch in ihrer Ansteuerung und elektrischen Eigenschaften auf. Die Potentiometer des Typs DS1803-100 werden über zwei Leitungen mittels I²C angesteuert und haben einen Gesamtwiderstand von 100 kΩ. Uber die Pins A0, A1 und A2 des ICs kann die Adresse im ¨

I

2C-Bus festgelegt werden. Uber die Datenleitung (SDA) werden dann mit jedem Takt der seriellen ¨

Clock am SCL-Pin die einzelnen Datenbits an die zwei 8-Bit-Register des ICs übertragen. Hat
der IC alle Datenbits erhalten, bestatigt er auf der Datenleitung, dass die ¨ | Ubertragung erfolgreich ¨
war. Für die Ansteuerung des ICs wird zunachst das allgemeine Kontrollbyte (0101) ¨ | 2 gefolgt
von der Adresse des Chips und einer Null für das Schreiben oder einer Eins für das Lesen der
Register übersendet. Als nachstes wird das zu beschreibende Potentiometer ausgew ¨ | ahlt. Dabei steht ¨

(10101001)2 für Pot-0, (10101010)2 für Pot-1 und (10101111)2 für Pot-0 und Pot-1. Zuletzt wird das Datenbyte und somit der neue Wert des Potentiometers übertragen. [28, S. 1-10]

Die Potentiometer des Typs MCP42010 werden hingegen mittels SPI angesteuert. Angesprochen wird der IC in diesem Fall nicht über eine Busadresse, sondern über den Chip-Select-Pin (CS-Pin). Ist der CS-Pin Low, konnen die Datenbits über die Datenleitung am SI-Pin und das Taktsignal ¨ am SCK-Pin in das 16-Bit-Schieberegister geschrieben werden. Bei der Datenübertragung wird
zunachst das Kontrollbyte übertragen. ¨ | Uber dieses Kontrollbyte kann bestimmt werden, ob der ¨

IC abgeschaltet (XX10XX)2 oder Daten in das Register geschrieben werden sollen (XX01XX)2. Der Buchstabe X steht dabei erneut für einen beliebigen Wert. Zudem wird über die Endung des
Kontrollbytes das zu verandernde Potentiometer ausgew ¨ | ahlt. Dabei steht die Endung (01) ¨ | 2 für
Pot-0, die Endung (10)2 für Pot-1 und die Endung (11)2 für Pot-0 und Pot-1. Im Gegensatz zu den DS1803-100 besitzen die MCP42010 einen Gesamtwiderstand von 10 kΩ. [29, S. 1-18]

Die elektrischen Eigenschaften der beiden Potentiometer weichen ebenfalls leicht voneinander ab. Die typische Versorgungsspannung der DS1803-100 Potentiometer liegt zwischen 3 V und 5 V, wohingegen die der MCP42010 zwischen 2,7 V und 5,5 V liegt. [28, S. 1] [29, S. 1] Im Gegensatz zu mechanischen Potentiometern sind beide ICs in ihrer minimalen und maximalen Spannung, die
an den Kontakten anliegen kann, beschrankt. Bei den Potentiometern des Typs DS1803-100 bel ¨ | | auft ¨
sich die minimale Spannung auf GND −0, 5 V und die maximale Spannung auf VCC +0, 5 V. [28,
S. 6] Bei den Potentiometern des Typs MCP42010 liegt die minimale Spannung bei GND −0, 6 V und die maximale Spannung bei VCC + 1 V. [29, S. 5] Somit sind beide Typen in der Lage, die Ausgangssignale des AD9833 weiterzuleiten und konnen für den Spannungsteiler vor der ¨ Verstarkerschaltung verwendet werden. ¨
Für die Verstarkerschaltung selbst wird ein Operationsverst ¨ | arker des Typs OPA1612 der Firma ¨
Texas Instruments verwendet. Bei diesem handelt es sich um einen kostengünstigen aber dennoch leistungsstarken High-Performance Bipolar-Input Audio OPV. [30, S. 1] Die elektrischen sowie nichtelektrischen Eigenschaften dieses Bauteils sind in Tabelle 10 aufgelistet.

Dieser OPV eignet sich durch seine hohe Bandbreite und Slew Rate in Kombination mit der geringen Rauschdichte und Verzerrung ideal, um hochfrequente Spannungssignale ohne einen

Tabelle 10: Elektrische und nichtelektrische Eigenschaften des OPA1612 der Firma Texas Instruments [30, S. 1-4]

Elektrische Eigenschaften

Bandbreite (GBW) | | 40 MHz
Rauschdichte | 1, 1 nV/

√
| | Hz bei 1 kHz
Verzerrung | | 1, 5 · 10⁻⁵ % bei 1 kHz
Slew Rate | | 27 V/μs
Versorgungsspannung | | ±2, 25 V bis ±18 V
Versorgungsstrom | | 3, 6 mA

Nichtelektrische Eigenschaften

Anzahl an Verstarkern je IC | 2 ¨
Anzahl an Kontakten | | 8

signifikanten Qualitatsverlust zu verst ¨ | arken. Betrieben wird der OPV als ein nicht invertierender ¨
Verstarker. Eine derartige Verst ¨ | arkerschaltung ist in der Abbildung 9 zu sehen. Dabei wird die am ¨
nicht invertierenden Eingang anliegende Spannung Ue | um einen bestimmten Faktor V verstarkt ¨
und steht dann als verstarktes Spannungssignal ¨ | Ua | am Ausgang des OPVs zur Verfügung. Der
Verstarkungsfaktor ¨ | V berechnet sich dabei durch folgende Formel:

V =

Ua

Ue

= 1 +

R1

R2

(10)

Durch die Veranderung des Verh ¨ | altnisses zwischen den beiden Widerst ¨ | anden ¨ | R1 und R2 kann nach
dieser Formel also die Verstarkung des OPVs eingestellt werden. [25, S. 235] ¨

Für das akustische und visuelle Feedback wird erneut ein passiver Buzzer sowie ein adressierbarer LED-Streifen des Typs WS2812B verwendet.

### 6.2. Schaltungsentwicklung

Nach der Auswahl der benotigten Komponenten für die Realisierung des Funktionsgenerators ¨ mittels DDS wird in diesem Abschnitt der eigentliche Schaltungsaufbau beschrieben. Hierbei wird der finale Schaltungsaufbau unter Verwendung der digitalen Potentiometer des Typs MCP42010 referenziert. Der vollstandige Schaltplan ist in den Abbildungen 26 bis 29 auf den Seiten 74 bis 77 ¨ im Anhang zu finden.

Analog zur im Kapitel 5 beschriebenen Variante werden die Parameter der einzelnen Gruppen über den Master, also das Waveshare ESP32-S3 HMI, mittels einer microSD-Karte eingelesen und über eine UART-Schnittstelle an den Slave, also das ESP32 Devkit C V4, übertragen. Diese Verbindung ist auf Abbildung 26 auf der Seite 74 im Anhang zu erkennen. Der Master (U1) sowie der Slave (U2) sind über die jeweiligen UART-Anschlüsse der einzelnen Boards miteinander verbunden. Dabei ist die TX-Datenleitung des Masters (GPIO 43) mit der RX-Datenleitung des Slaves (GPIO 16) und die RX-Datenleitung des Masters (GPIO 44) mit der TX-Datenleitung des Slaves (GPIO 17) verbunden. Uber ein 9 V bis 36 V auf 5,2 V DC-DC Buck Converter werden beide ¨

Komponenten mit Spannung versorgt. Mittels GPIO 15 steuert der Master den Buzzer, welcher ein akustisches Feedback für Eingaben auf dem Display ausgibt. Alle weiteren Komponenten werden

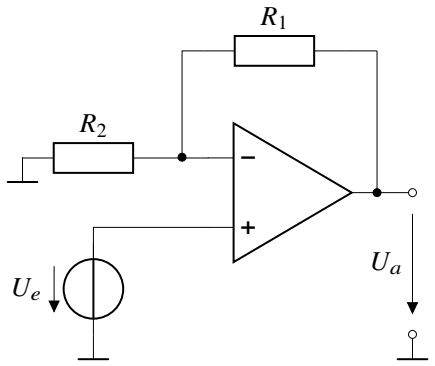
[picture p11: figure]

Abbildung 9: Nicht invertierende Verstarkerschaltung ¨

einzig durch den Slave angesteuert und sind demnach nicht mit dem Master verbunden. So steuert der Slave beispielsweise den adressierbaren LED-Streifen, für das visuelle Feedback an den Nutzer, über GPIO 23 an. Da der Funktionsgenerator, wie in FA-1 gefordert, über zwei Ausgangskanale ¨ verfügen soll, muss für jeden Kanal ein dedizierter AD9833-DDS-IC verwendet werden. Die Spannungsversorgung der beiden ICs erfolgt über den 3,3 V Pin des Slaves. Für die Ansteuerung der beiden AD9833-Module werden eine Datenleitung (SDATA), die mit GPIO 19 verbunden ist, eine Taktleitung (SCLK), welche mit GPIO 21 verbunden ist, sowie zwei Leitungen für die Chipauswahl (FSYNC1 und FSYNC2), die mit GPIO 18 und GPIO 5 verbunden sind, benotigt. ¨ Da sich beide ICs die gleiche Daten- und Taktleitung teilen, wird über die FSYNC-Pins bestimmt, welches der beiden Module mit Daten beschrieben werden soll. Ist der Zustand von FSYNC1 Low, so ist das AD9833-Modul des ersten Kanals ausgewahlt und kann mit Daten beschrieben werden. ¨ Ist der Zustand von FSYNC2 Low, so ist das AD9833-Modul des zweiten Kanals ausgewahlt und ¨ kann mit Daten beschrieben werden. Zusatzlich zu den einzelnen FSYNC-Pins für jedes Modul ¨ gibt es einen gemeinsamen FSYNC SYNC Anschluss, der mit GPIO 22 des Slaves verbunden ist und für die Synchronisation der beiden Module verwendet wird. Ohne eine Synchronisation über den SYNC-Pin würden die beiden Module zu unterschiedlichen Zeitpunkten initialisiert und
freigegeben werden, wodurch die beiden Ausgangssignale zeitlich verschoben waren. Dies h ¨ | atte ¨
einen negativen Einfluss auf die Phasenbeziehung der beiden Signale zueinander und würde dazu führen, dass die beiden Spannungen stets um eine gewisse Phase verschoben waren. [11, S. 3-4] ¨

Die genaue Verschaltung der AD9833-Module sowie der einzelnen FSYNC-Pins ist in Abbildung 27 auf Seite 75 im Anhang zu sehen. Wie bereits erwahnt, werden beide ICs sowohl mit der ¨ Datenleitung (SDA) als auch mit der Taktleitung (SCLK) verbunden. Da beide AD9833-Module jeweils nur über einen FSYNC-Anschluss verfügen, müssen die Leitungen für FSYNC1, FSYNC2 und FSYNC SYNC so miteinander verschaltet werden, dass der IC des ersten Kanals sowohl durch FSYNC1 als auch durch FSYNC SYNC und der IC des zweiten Kanals sowohl durch FSYNC2 als auch durch FSYNC SYNC ausgewahlt werden kann. Zur Umsetzung dieses Verhaltens werden die ¨
Dioden D1 bis D4 sowie die beiden Widerstande R3 und R4 verwendet. Die Widerst ¨ | ande R3 und R4 ¨
ziehen die FSYNC-Pins der AD9833-Module standardmaßig auf High. Wird nun beispielsweise ¨ FSYNC1 oder FSYNC2 auf Low gesetzt, liegt am jeweiligen FSYNC-Pin eine Spannung von ca. 0,7 V an, was dem Low-Zustand entspricht. Die Dioden D2 und D3 verhindern dabei, dass die weiterhin auf High liegende FSYNC SYNC-Leitung die Pins zurück auf High zieht. Analog dazu werden beide FSYNC-Pins auf Low gezogen, wenn FSYNC SYNC auf Low gesetzt wird. Die Dioden D1 und D4 verhindern hierbei, dass die einzelnen FSYNC-Leitungen (FSYNC1 und FSYNC2) ihre jeweiligen FSYNC-Pins wieder auf High ziehen.

Wie in der Abbildung zu erkennen ist, werden zudem die zwei REF-Pins, an denen das Taktsignal des auf jedem Modul vorhandenen 25 MHz-Quarz abgegriffen werden kann, miteinander verbunden. Da jeder Quarz eine Genauigkeit von ca. 50 ppm besitzt, kann es unter der Verwendung eines Quarzes pro Modul zu einem sogenannten Phasendrift kommen.[27] Dieser tritt auf, da der AD9833 auf Grundlage des Taktsignals des Quarzes die Ausgangsfrequenz modelliert. Weichen diese Taktsignale voneinander ab, geben die Module am Ausgang Signale mit unterschiedlichen Frequenzen aus. Dies sorgt dafür, dass die Signale bei der Betrachtung auf einem Oszilloskop langsam auseinanderlaufen, wodurch keine feste Phasenverschiebung erreicht werden kann. Der

Effekt nimmt mit steigender Frequenz immer weiter zu. Dieser Effekt ist in Abbildung 30 und 31 auf den Seiten 78 und 79 im Anhang zu erkennen. So liegt die Phasenverschiebung bei einer Ausgangsfrequenz von 50 Hz nach 5 Minuten bei ca. 16°, obwohl die beiden ICs zum Zeitpunkt

t = 0 s keine Phasenverschiebung aufgewiesen haben. Bei einer Ausgangsfrequenz von 500 Hz steigt die Phasenverschiebung nach 5 Minuten bereits auf ca. 155° an. Um dieses Problem zu

beheben, wird auf einem der beiden ICs der Quarz entfernt und die beiden REF-Pins miteinander verbunden. Dadurch teilen sich beide Module nun das gleiche Taktsignal und konnen synchron ¨ betrieben werden. Laut Hersteller ist es dabei besonders wichtig, dass die Abstande des Taktgebers ¨ und der DDS-Chips nahezu identisch sind, da große Unterschiede in den Abstanden erneut zu ¨ einer unbeabsichtigten Phasenverschiebung führen konnten. [11, S. 3-4] Dies ist in Abbildung 10 ¨ dargestellt.

Der Output der beiden AD9833-Module wird über zwei einzelne Leitungen an zwei MCP42010 Potentiometer weitergeleitet. Die Verschaltung dieser Potentiometer ist in Abbildung 28 auf Seite 76 im Anhang zu sehen. Beide ICs sind dabei erneut an die gleiche Datenleitung (SDATA) und Taktleitung (SCLK) angeschlossen. Bei diesen Leitungen handelt es sich jedoch nicht um die Leitungen, welche für die Ansteuerung der DDS-ICs verwendet werden. Diese Trennung wurde vorgenommen, da die gemeinsame Nutzung identischer Daten- und Taktleitungen durch die AD9833-Module und die MCP42010-Potentiometer zu gegenseitigen Storungen führt, wodurch ¨
keine zuverlassige und gezielte Steuerung der einzelnen Bauteile m ¨ | oglich ist. Aus diesem Grund ¨
werden für die digitalen Potentiometer eine eigene Datenleitung auf GPIO 26 sowie eine eigene Taktleitung auf GPIO 25 vorgesehen. Analog zu den FSYNC-Pins der DDS-ICs erfolgt die Auswahl der Potentiometer über die beiden Chip-Select-Leitungen CS1 und CS2. CS1 steuert dabei das Potentiometer des ersten Kanals, wahrend CS2 das Potentiometer des zweiten Kanals ¨ ansteuert. Die Leitungen sind dabei mit Pin 4 (CS1) beziehungsweise Pin 0 (CS2) des Slaves
verbunden. Die Widerstande R5 und R6 fungieren als Pull-up-Widerst ¨ | ande und stellen sicher, dass ¨
die Low-aktiven CS-Pins der Potentiometer standardmaßig auf einem High-Pegel liegen, solan- ¨ ge CS1 beziehungsweise CS2 nicht aktiv auf Low gezogen werden. Laut Datenblatt müssen der Reset- sowie Shutdown-Pin (Pins 11 und 12 des ICs) bei Nichtverwendung auf High gezogen werden. Dazu werden beide Pins mit der Versorgungsspannung (3,3 V) verbunden. [29, S. 12] Um aus den Potentiometern einen Spannungsteiler zu realisieren, mit dem die Eingangsspannung des Operationsverstarkers gesteuert werden kann, werden die Ausgangssignale der AD9833-Module ¨

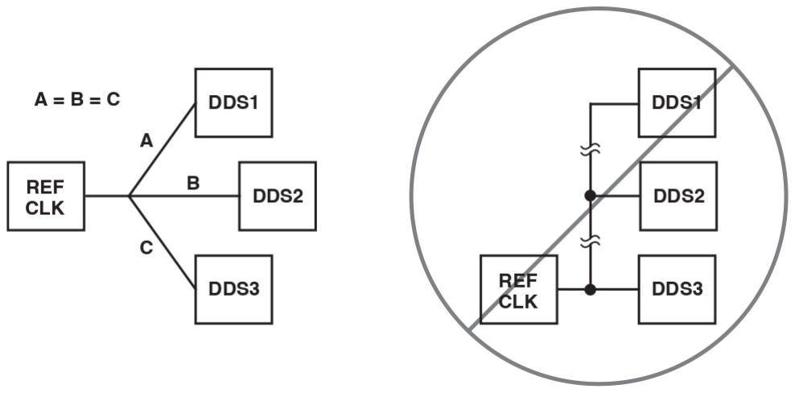
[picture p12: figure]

Abbildung 10: Referenztakt-Verteilung bei der Verwendung eines einzelnen Taktgebers für mehrere DDS-ICs [31, S. 1]

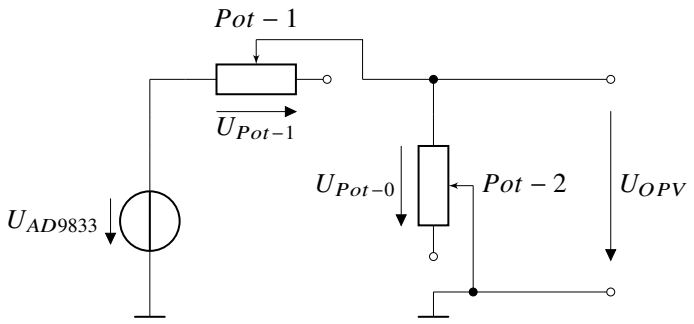
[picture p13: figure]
UAD9833; UOPV; Pot − 1; UPot−1; UPot−0; Pot − 2

Abbildung 11: Vereinfachte Darstellung des Spannungsteilers mittels der digitalen Potentiometer MCP42010

jeweils mit dem B-Anschluss des zweiten Potentiometers (PB1) des ICs verbunden. Der Wiper des zweiten Potentiometers (PW1) wird anschließend mit dem B-Anschluss des ersten Potentiometers (PB0) verbunden, wahrend der Wiper des ersten Potentiometers (PW0) mit GND verbunden ¨ wird. Der Eingang des Operationsverstarkers wird an der Verbindung zwischen PW1 und PB0 ¨ angeschlossen. Eine übersichtliche Darstellung des Spannungsteilers ist in Abbildung 11 zu sehen.
Uber das Verh ¨ | altnis der Widerst ¨ | ande von Pot-0 und Pot-1 kann die Eingangsspannung des Opera- ¨

tionsverstarkers eingestellt und somit die Amplitude des Ausgangssignals gesteuert werden. [25, ¨
S. 165]

Der Grund für die Nichtverwendung der digitalen Potentiometer des Typs DS1803-100 sind zwei konkrete bauteilspezifische Eigenschaften, welche bei der Entwicklung des Funktionsgenerators hervorgetreten sind. Da es sich bei digitalen Potentiometern nicht um klassische mechanische Bauteile handelt, besitzen sie im Gegensatz zu diesen eine bestimmte Grenzfrequenz. Digitale Potentiometer bestehen im Wesentlichen aus Widerstanden und Schaltern. Der Widerstand entlang ¨
des Signalpfades bildet zusammen mit den parasitaren Kapazit ¨ | aten der Schalter, den Pin- und ¨
Platinenkapazitaten einen RC-Tiefpassfilter. Dieser Tiefpassfilter bestimmt die maximale Wech- ¨ selstromfrequenz, die durch das Potentiometer geleitet werden kann, bevor das Ausgangssignal um mehr als 3 dB gedampft wird. Dabei besitzen Potentiometer mit geringem Gesamtwiderstand ¨ eine hohe und Potentiometer mit einem großen Gesamtwiderstand eine geringe Grenzfrequenz. Für die Potentiometer des Typs DS1803-100 mit einem Gesamtwiderstand von ca. 100 kΩ liegt die Grenzfrequenz bei ca. 70 kHz. [32, S. 4] Dies würde bedeuten, dass der Spannungsteiler ab dieser Frequenz die Ausgangsspannung des OPVs nicht korrekt steuern kann. Zudem fiel bei Tests auf, dass die DS1803-100-Potentiometer bei hoheren Frequenzen für nicht unerhebliche Verzerrungen ¨ des Ausgangssignals verantwortlich sind. Dies ist in Abbildung 32 auf Seite 80 im Anhang zu erkennen. Da die MCP42010 Potentiometer einen Gesamtwiderstand von ca. 10 kΩ besitzen, liegt die Grenzfrequenz laut Datenblatt bei ca. 1 MHz. Zudem tritt unter Verwendung dieser Potentiometer bei hohen Ausgangsfrequenzen keine nennenswerte Verzerrung des Spannungssignals auf.

Da das AD9833-Modul nur positive Spannungswerte ausgeben kann, muss das Signal vor der Verstarkerschaltung um den Nullpunkt ausgesteuert werden. Hierzu werden, wie in Abbildung 26 ¨ auf Seite 74 im Anhang zu sehen ist, zwei 100 nF Keramikkondensatoren C1 und C2 verwendet. Diese Koppelkondensatoren entfernen das Gleichtaktsignal und sorgen für ein nullsymmetrisches

Spannungssignal am Eingang des Operationsverstarkers. Die Widerst ¨ | ande R1 und R2 dienen ¨
als DC-Bias-Widerstande und stellen nach den AC-Koppelkondensatoren C1 und C2 einen de- ¨
finierten Gleichspannungspfad nach Masse bereit. Ohne diese Widerstande k ¨ | onnte kein stabiler ¨
Gleichspannungs-Arbeitspunkt an den Eingangen des Operationsverst ¨ | arkers sichergestellt werden, ¨
was zu einem undefinierten Arbeitspunkt und einer Sattigung des Ausgangs führen k ¨ | onnte. ¨

Die nullsymmetrischen Spannungssignale werden an die nicht invertierenden Kontakte des in Abbildung 29 auf Seite 77 im Anhang dargestellten Operationsverstarkers weitergeleitet. Damit ein ¨ in NFA-5 geforderter Spannungsbereich abgedeckt werden kann, wurde entschieden, das Spannungssignal auf einen Bereich von ±10 V zu verstarken. Um diesen Spannungsbereich aussteuern ¨
zu konnen, wird der OPV mittels einer symmetrischen Versorgungsspannung von ¨ | ±15 V, die über
Kontakte an den Laborarbeitsplatzen des Messtechniklabors abgegriffen wird, betrieben. Da die ¨ Kondensatoren C1 und C2 zusammen mit den Widerstanden R1 und R2 einen RC-Hochpass bil- ¨
den, muss der Verstarkungsfaktor ¨ | V der Verstarkerschaltung in der Lage sein, das bei niedrigen ¨
Frequenzen gedampfte Ausgangssignal des Spannungsteilers zu verst ¨ | arken. Bei einer Frequenz ¨
von 1 Hz betragt das Ausgangssignal im Sinusmodus ca. 287 mV (Top). Der OPV ben ¨ | otigt also ¨
einen Verstarkungsfaktor von ca. 34,84, um das Spannungssignal auf ¨ | ±10 V zu verstarken. Damit ¨
ein gewisser Sicherheitsabstand entsteht, wird durch die Dimensionierung der Widerstande R7 bis ¨ R10 ein Verstarkungsfaktor von ca. 37,36 festgelegt. ¨

V = 1 +

12 kΩ
330 Ω
= 37, 36 | (11)

Anhand der Slew Rate und der Bandbreite des OPVs lasst sich die maximal erreichbare Ausgangs- ¨ frequenz unter diesem Verstarkungsfaktor berechnen. Für die Sinusausgabe berechnet sich diese ¨ wie folgt: [33]

fmax =

Slew Rate

2 · π · Ausgangsspannung

=

27 V
μs
- 10⁶

2 · π · 10 V

= 430 kHz | (12)

Da bei einem Verstarkungsfaktor von 37,36 und einer Frequenz von 430 kHz eine Bandbreite von ¨ gerade einmal 16 MHz benotigt wird, ergibt sich die Grenzfrequenz einzig durch die Slew Rate ¨ des OPVs. Bei der Verstarkung des Rechtecksignals muss sich die Spannung am Ausgang des ¨
OPVs (Va) bei einer Verstarkung auf ¨ | ±10 V um das Zweifache von Va andern. Dies wird nur mit ¨
der maximalen Anstiegsrate (Slew Rate) erreicht. Damit das Signal noch als rechteckig erkannt werden kann, sollte die Anstiegszeit kleiner als eine halbe Periodenzeit sein. Unter dem Grenzfall der halben Periodenzeit gilt: [33]

tr ise =

2 · Va

Slew Rate

⇒ tr ise =

T
2

=

1
2 · f

(13)

Somit ergibt sich eine Grenzfrequenz fmax von:

fmax =

Slew Rate

4 · Va

=

27 V
μs
- 10⁶

4 · 10 V

= 675 kHz | (14)

Für die eingestellte Verstarkung von 37,36 ergibt sich eine Grenzfrequenz von: ¨

fmax =

GBW

V

=

40 MHz
37, 36
= 1, 07 MHz | (15)

Da ein Rechtecksignal jedoch nicht nur aus einer Grundschwingung sondern aus einer Uberlagerung ¨

von vielen Oberschwingungen besteht, müssen diese Schwingungen ebenfalls berücksichtigt werden. Ab der dritten Oberschwingung kann das Signal als rechteckformig identifiziert werden, ¨ wodurch diese Oberschwingung ebenfalls durch den OPV verstarkt werden muss. [34, S. 128-130] ¨ Dadurch ergibt sich in Abhangigkeit der Bandbreite eine neue Grenzfrequenz von: ¨

fmax =

1, 07 MHz
3
≈ 357 kHz | (16)

Somit sollte der OPV in der Lage sein, bis zu einer Frequenz von 357 kHz ein erkennbares Rechtecksignal zu verstarken. ¨

Nach dem OPV werden die Signale durch die 100 nF Keramikkondensatoren C3 und C4 (Abbildung 26 auf Seite 74 im Anhang) erneut um den Nullpunkt ausgesteuert. Hierbei werden keine
zusatzlichen Bias-Widerst ¨ | ande ben ¨ | otigt, da im Inneren des Oszilloskops ein hochohmiger Wider- ¨
stand mit Masse verbunden ist.
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

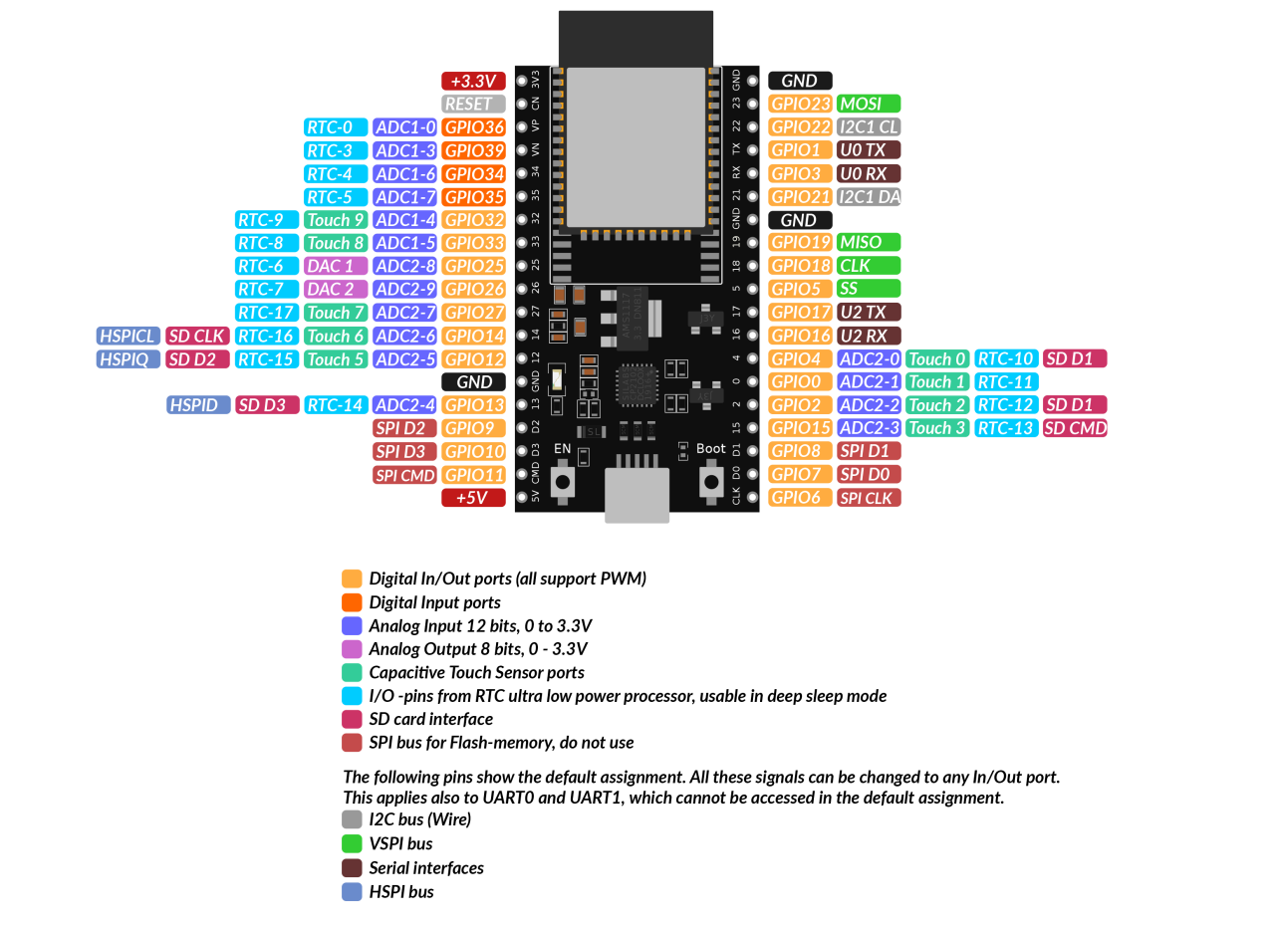
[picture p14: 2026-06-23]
docs/Pinouts/AZ-Delivery ESP32 DevKit C V4/Pinout ESP32 Dev Kit C V4.png

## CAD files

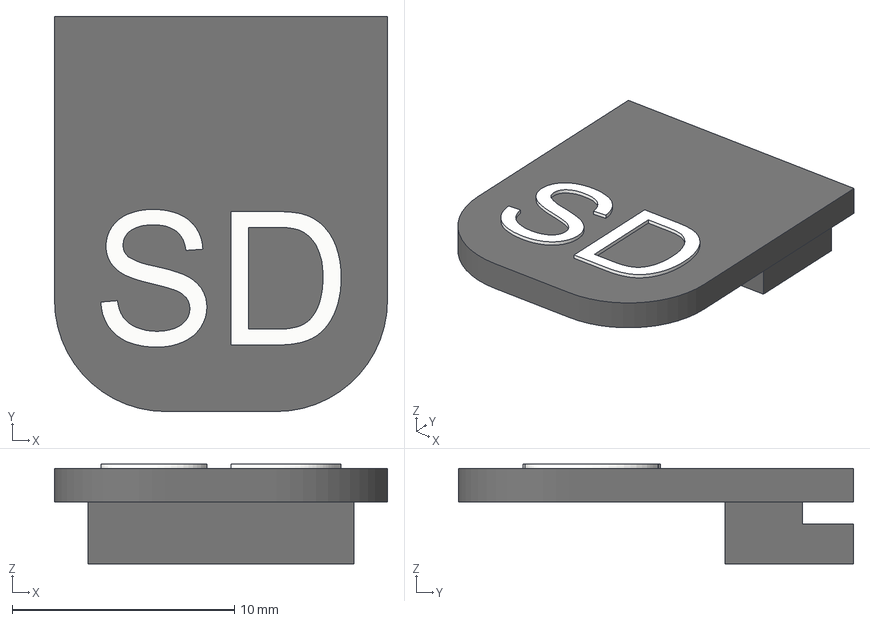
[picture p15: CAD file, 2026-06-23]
docs/3D-Design/Implementierungsmethode A (DAC)/Modelle/microSD-Holder.3mf
15.0 x 17.8 x 4.50 mm
Holder "D"
Holder "S"
Holder

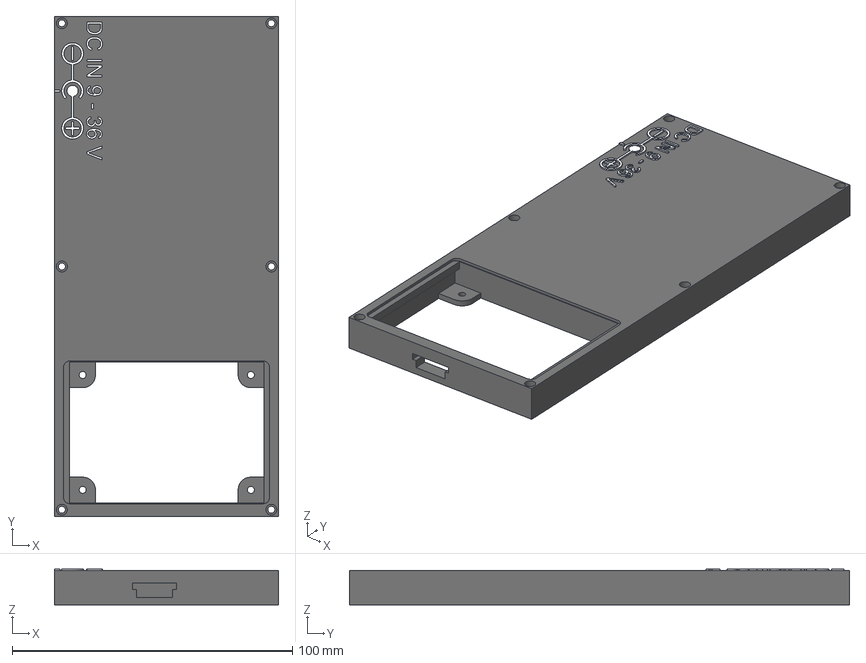
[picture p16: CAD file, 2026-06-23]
docs/3D-Design/Implementierungsmethode B (DDS)/Modelle/Deckel.3mf
80.0 x 178.4 x 12.7 mm
Deckel
Körper194
Körper195
Körper196
Körper197
Körper198
Körper199
Körper200
Körper201
Körper202
Körper203
Körper204
Körper205
Körper206
Körper207

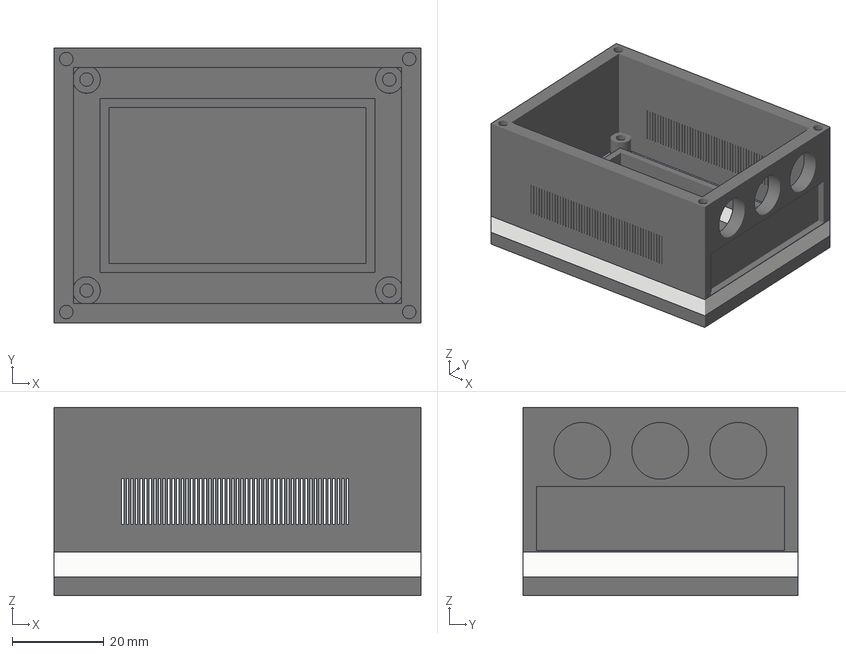
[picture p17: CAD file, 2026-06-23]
docs/3D-Design/Implementierungsmethode A (DAC)/Modelle/Korpus.3mf
80.0 x 60.0 x 41.0 mm
Körper (1) (1)
Körper (1) (2)
Körper (1) (3)
Körper (1) (4)
Körper (1) (5)
Körper (1)
Körper (2) (1)
Körper (2)
Körper

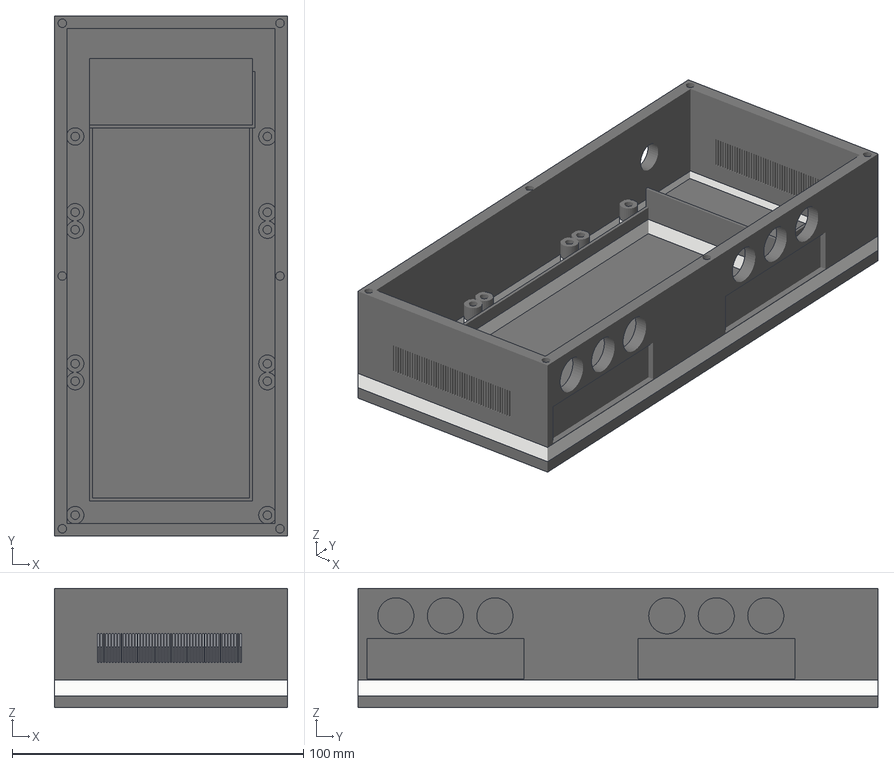
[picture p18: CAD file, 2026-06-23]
docs/3D-Design/Implementierungsmethode B (DDS)/Modelle/Korpus.3mf
80.0 x 178.4 x 41.0 mm
Körper (1) (1)
Körper (1) (2)
Körper (1)
Körper (2) (1)
Körper (2)
Körper (3) (1)
Körper (3) (2)
Körper (3) (3)
Körper (3) (4)
Körper (3) (5)
Körper (3) (6)
Körper (3)
Körper

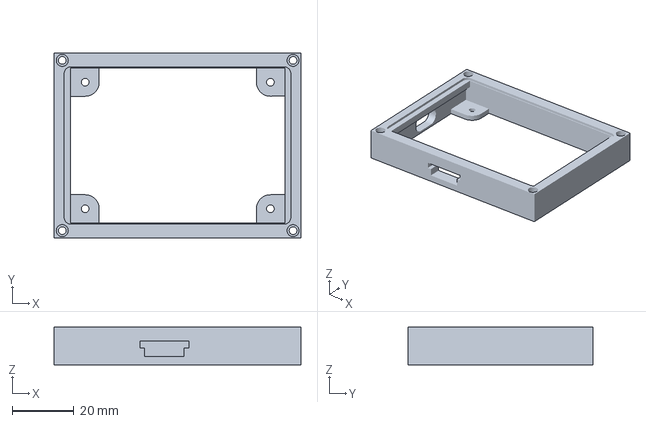
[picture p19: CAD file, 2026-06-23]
docs/3D-Design/Implementierungsmethode A (DAC)/Modelle/Deckel.3mf
80.0 x 60.0 x 12.2 mm

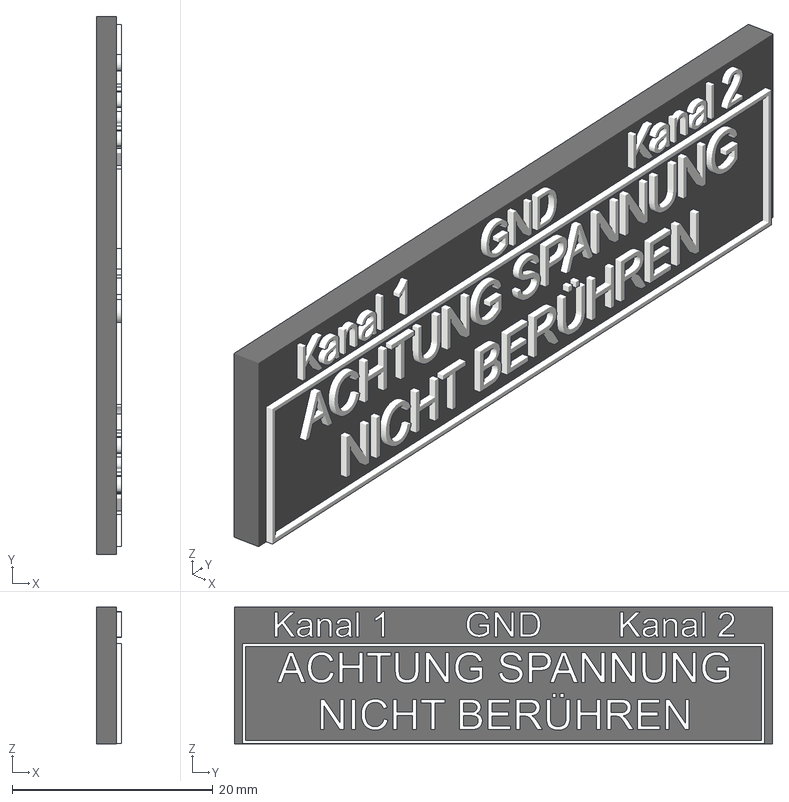
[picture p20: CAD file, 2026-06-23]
docs/3D-Design/Implementierungsmethode A (DAC)/Modelle/Textplakette.3mf
2.50 x 53.6 x 13.6 mm
Text (1)
Text (10)
Text (11)
Text (12)
Text (13)
Text (14)
Text (15)
Text (16)
Text (17)
Text (18)
Text (19)
Text (2)
Text (20)
Text (21)
Text (22)
Text (23)
Text (24)
Text (25)
Text (26)
Text (27)
Text (29)
Text (3)
Text (30)
Text (31)
Text (32)
Text (33)
Text (34)
Text (35)
Text (36)
Text (37)
Text (38)
Text (39)
Text (4)
Text (40)
Text (44)
Text (45)
Text (46)
Text (47)
Text (48)
Text (49)
Text (5)
Text (50)
Text (6)
Text (7)
Text (8)
Text (9)
Text

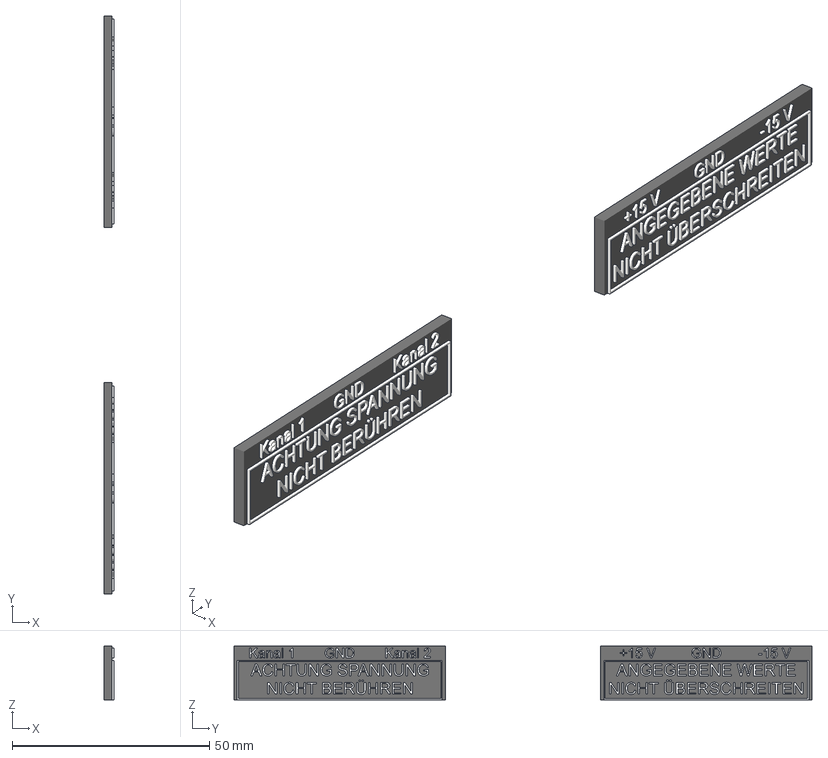
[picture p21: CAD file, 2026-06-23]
docs/3D-Design/Implementierungsmethode B (DDS)/Modelle/Textplaketten.3mf
2.50 x 146.6 x 13.6 mm
Körper124
Körper125
Körper126
Körper127
Körper128
Körper129
Körper130
Körper131
Körper132
Körper133
Körper134
Körper135
Körper136
Körper137
Körper138
Körper139
Körper140
Körper141
Körper142
Körper143
Körper144
Körper145
Körper146
Körper147
Körper148
Körper149
Körper150
Körper151
Körper152
Körper153
Körper154
Körper155
Körper156
Körper157
Körper158
Körper159
Körper160
Körper161
Körper162
Körper163
Körper164
Körper165
Körper166
Körper167
Körper168
Körper169
Körper170
Körper171
Text (1)
Text (10)
Text (11)
Text (12)
Text (13)
Text (14)
Text (15)
Text (16)
Text (17)
Text (18)
Text (19)
Text (2)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

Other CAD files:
docs/3D-Design/Implementierungsmethode B (DDS)/Modelle/microSD-Holder.3mf

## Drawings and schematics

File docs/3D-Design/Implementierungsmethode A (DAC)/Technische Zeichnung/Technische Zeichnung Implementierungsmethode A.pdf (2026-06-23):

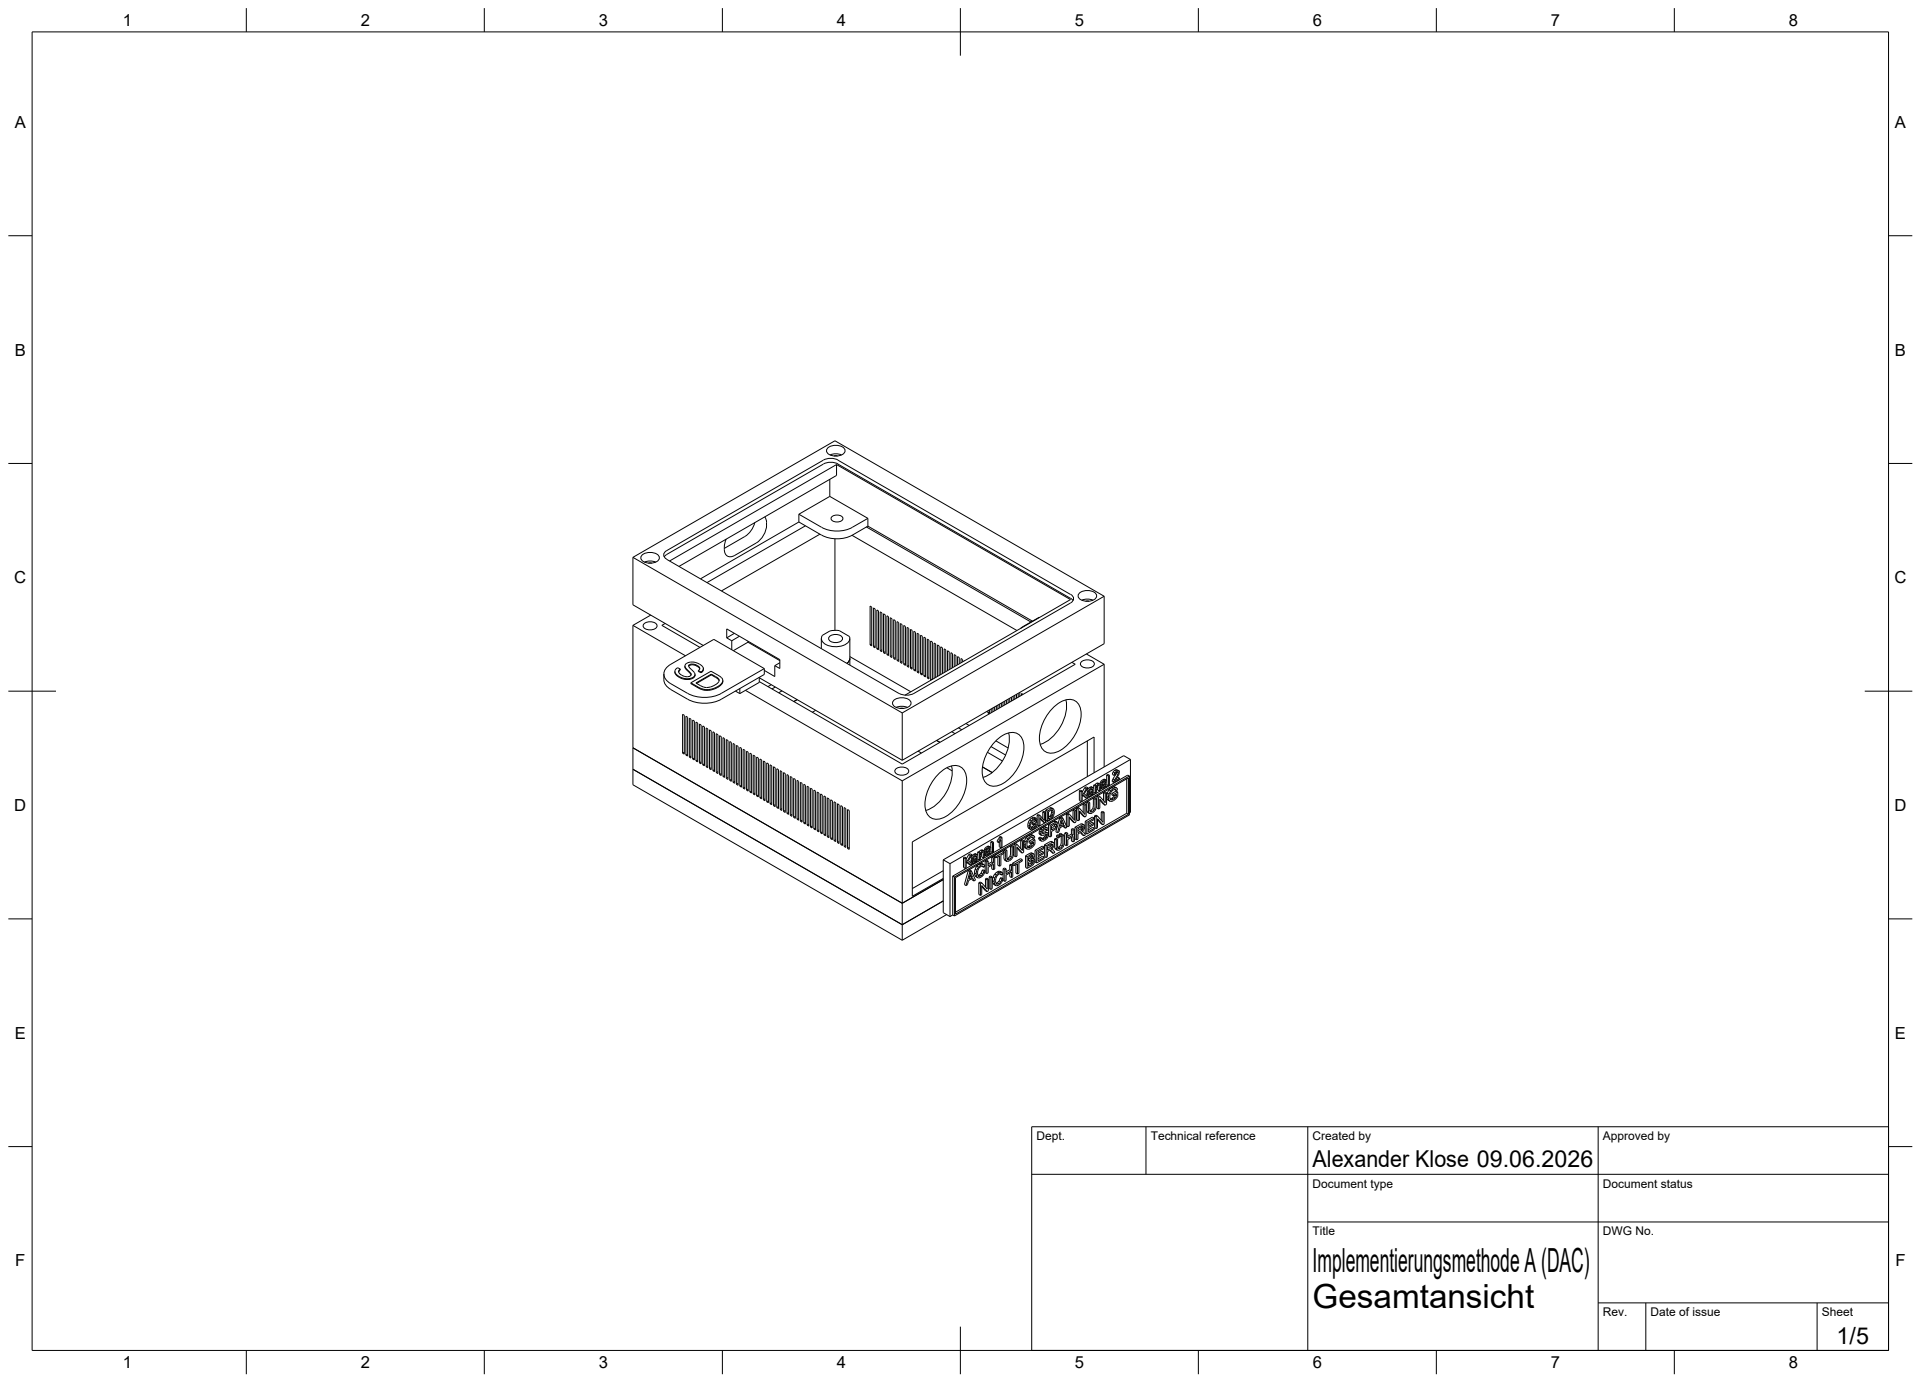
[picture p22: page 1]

Dept. | Technical reference | Created by Alexander Klose 09.06.2026 | Approved by

Document type | Document status

Title Implementierungsmethode A (DAC) Gesamtansicht | DWG No.

Rev. | Date of issue | Sheet

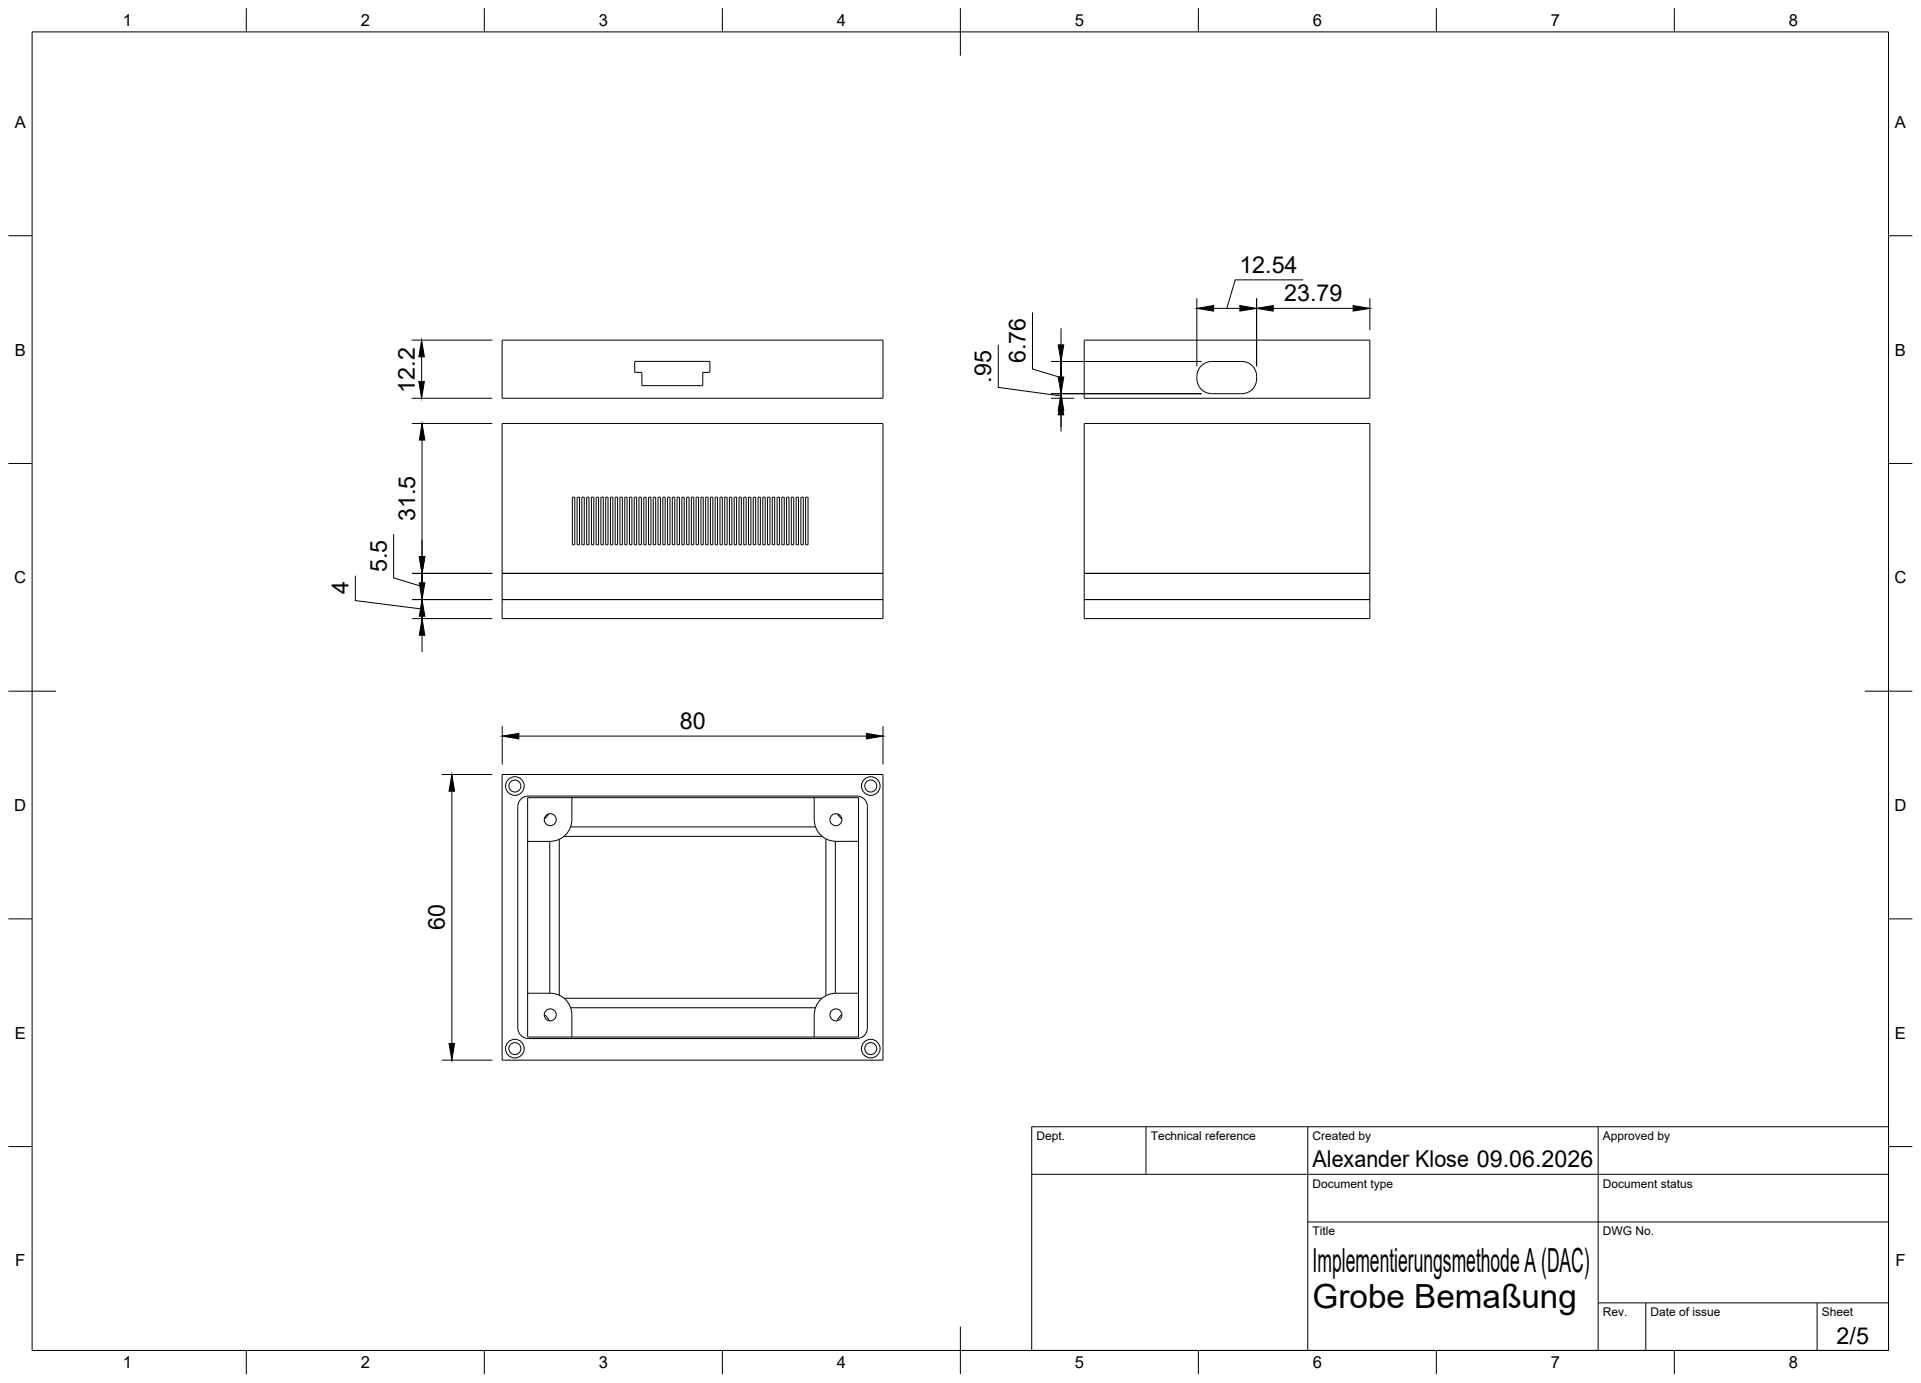
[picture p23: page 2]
Alexander Klose 12.2

Dept. | Technical reference | Created by 09.06.2026 | Approved by

Document type | Document status

Title Implementierungsmethode A (DAC) Grobe Bemaßung | DWG No.

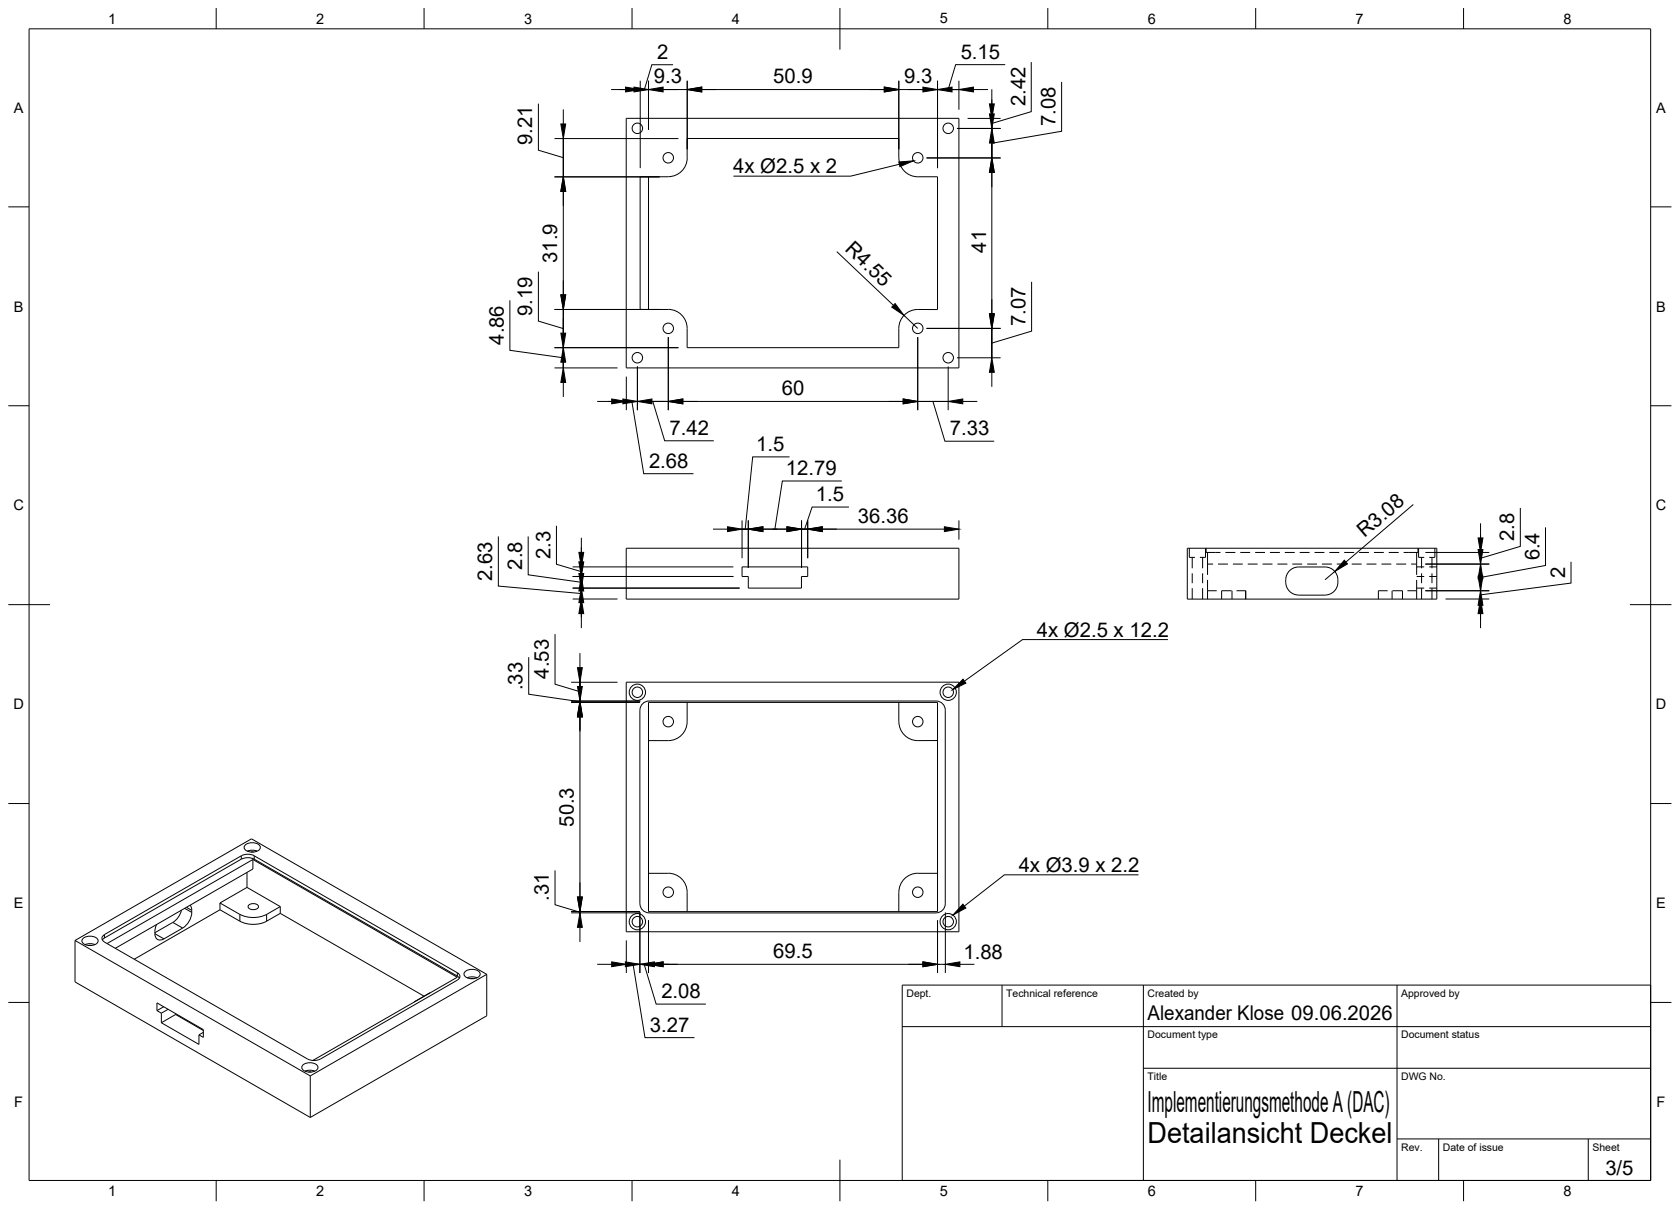
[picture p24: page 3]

Dept. | Technical reference | Created by Alexander Klose 09.06.2026 | Approved by

Document type | Document status

Title Implementierungsmethode A (DAC) Detailansicht Deckel | DWG No.

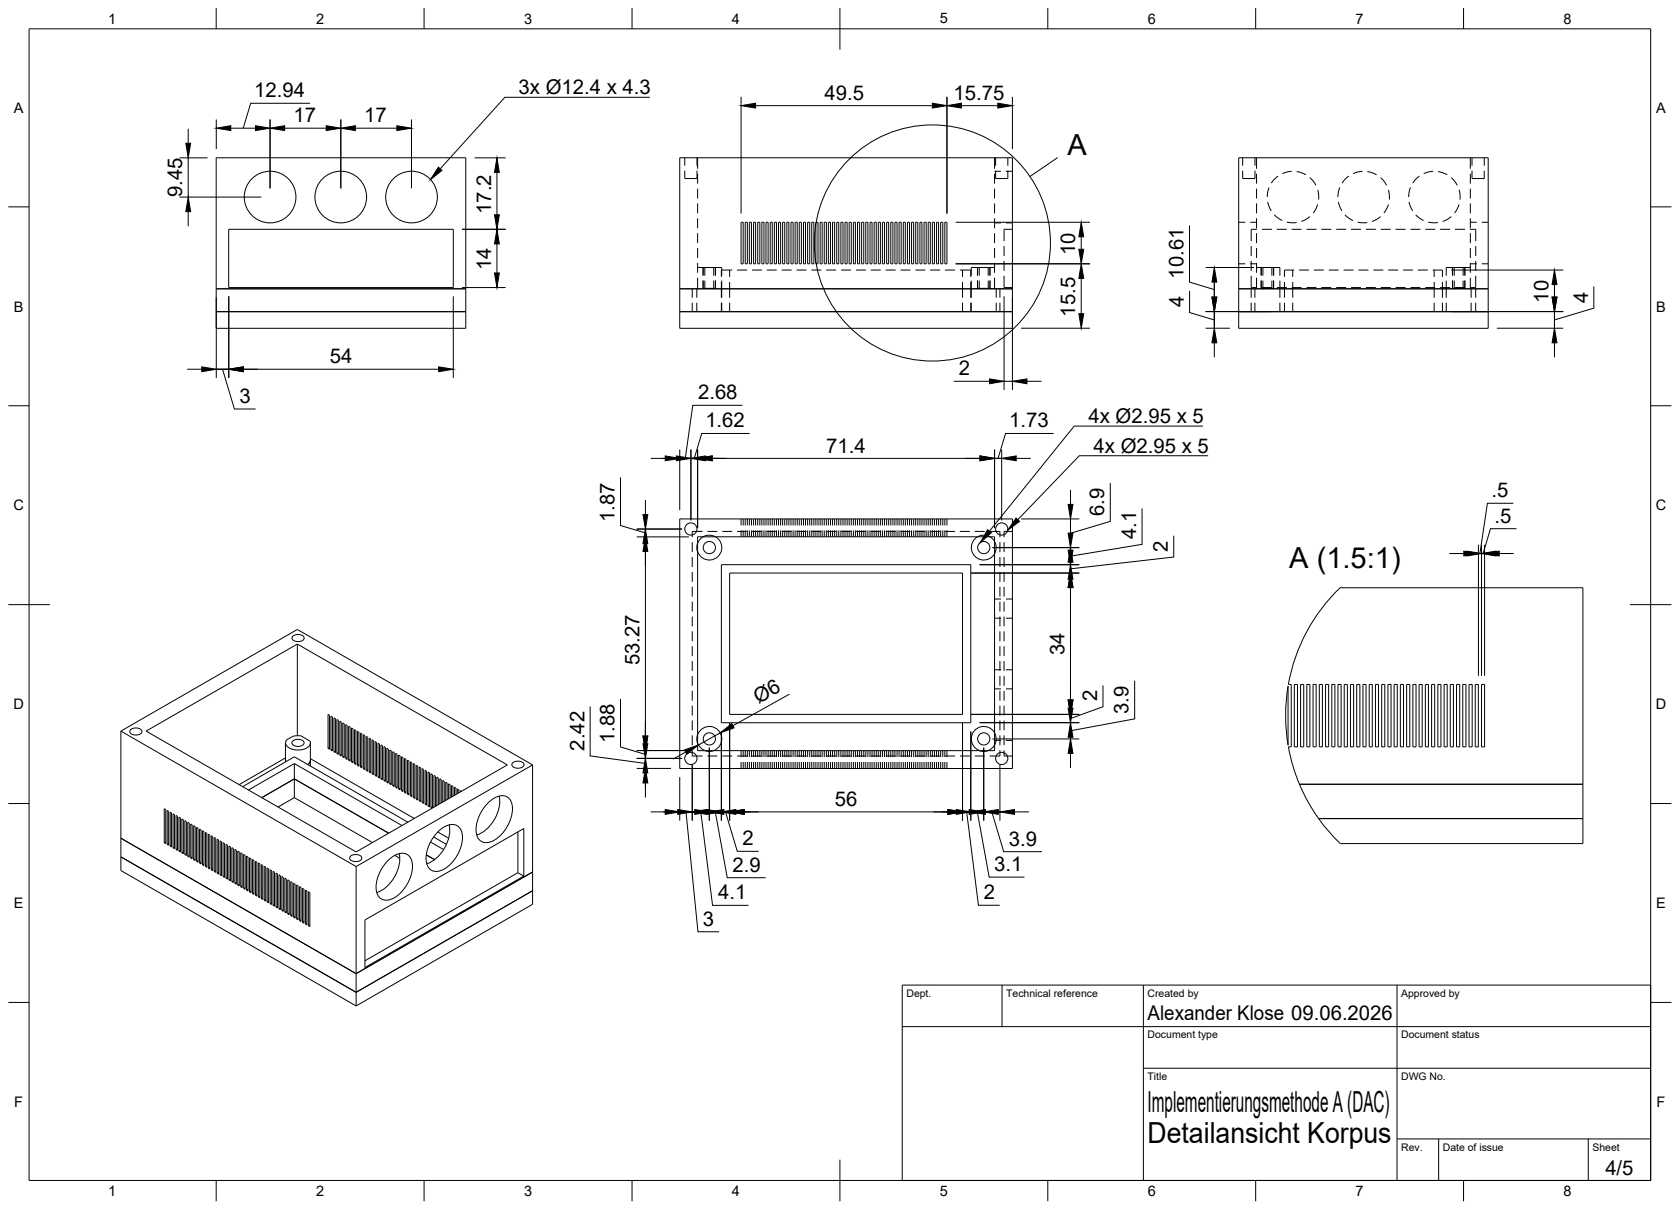
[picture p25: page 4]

Dept. | Technical reference | Created by Alexander Klose 09.06.2026 | Approved by

Document type | Document status

Title Implementierungsmethode A (DAC) Detailansicht Korpus | DWG No.

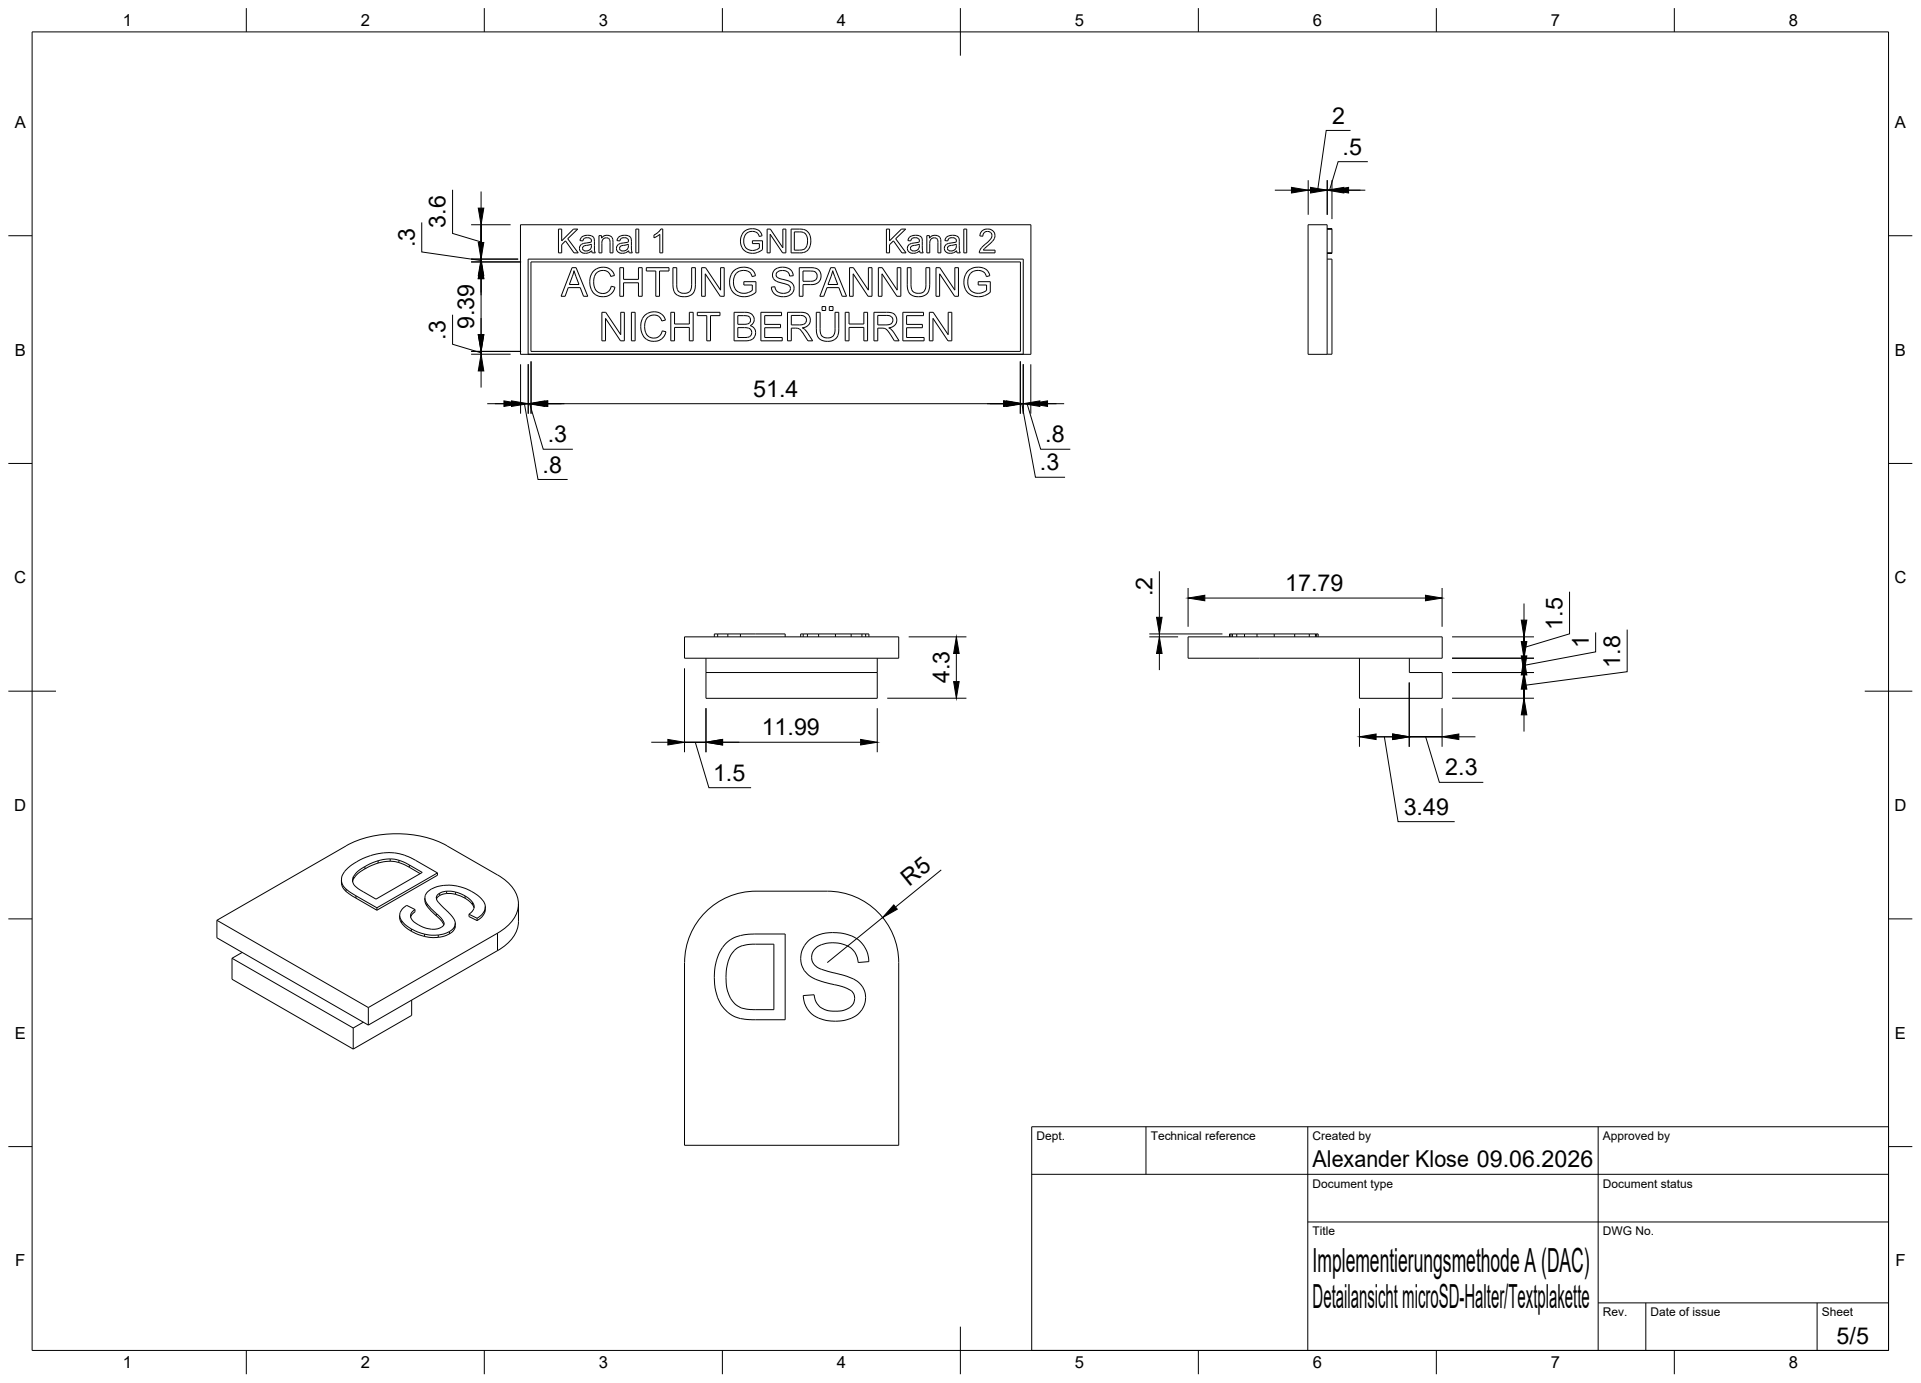
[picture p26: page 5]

Dept. | Technical reference | Created by Alexander Klose 09.06.2026 | Approved by

Document type | Document status

Title Implementierungsmethode A (DAC) Detailansicht microSD-Halter/Textplakette | DWG No.

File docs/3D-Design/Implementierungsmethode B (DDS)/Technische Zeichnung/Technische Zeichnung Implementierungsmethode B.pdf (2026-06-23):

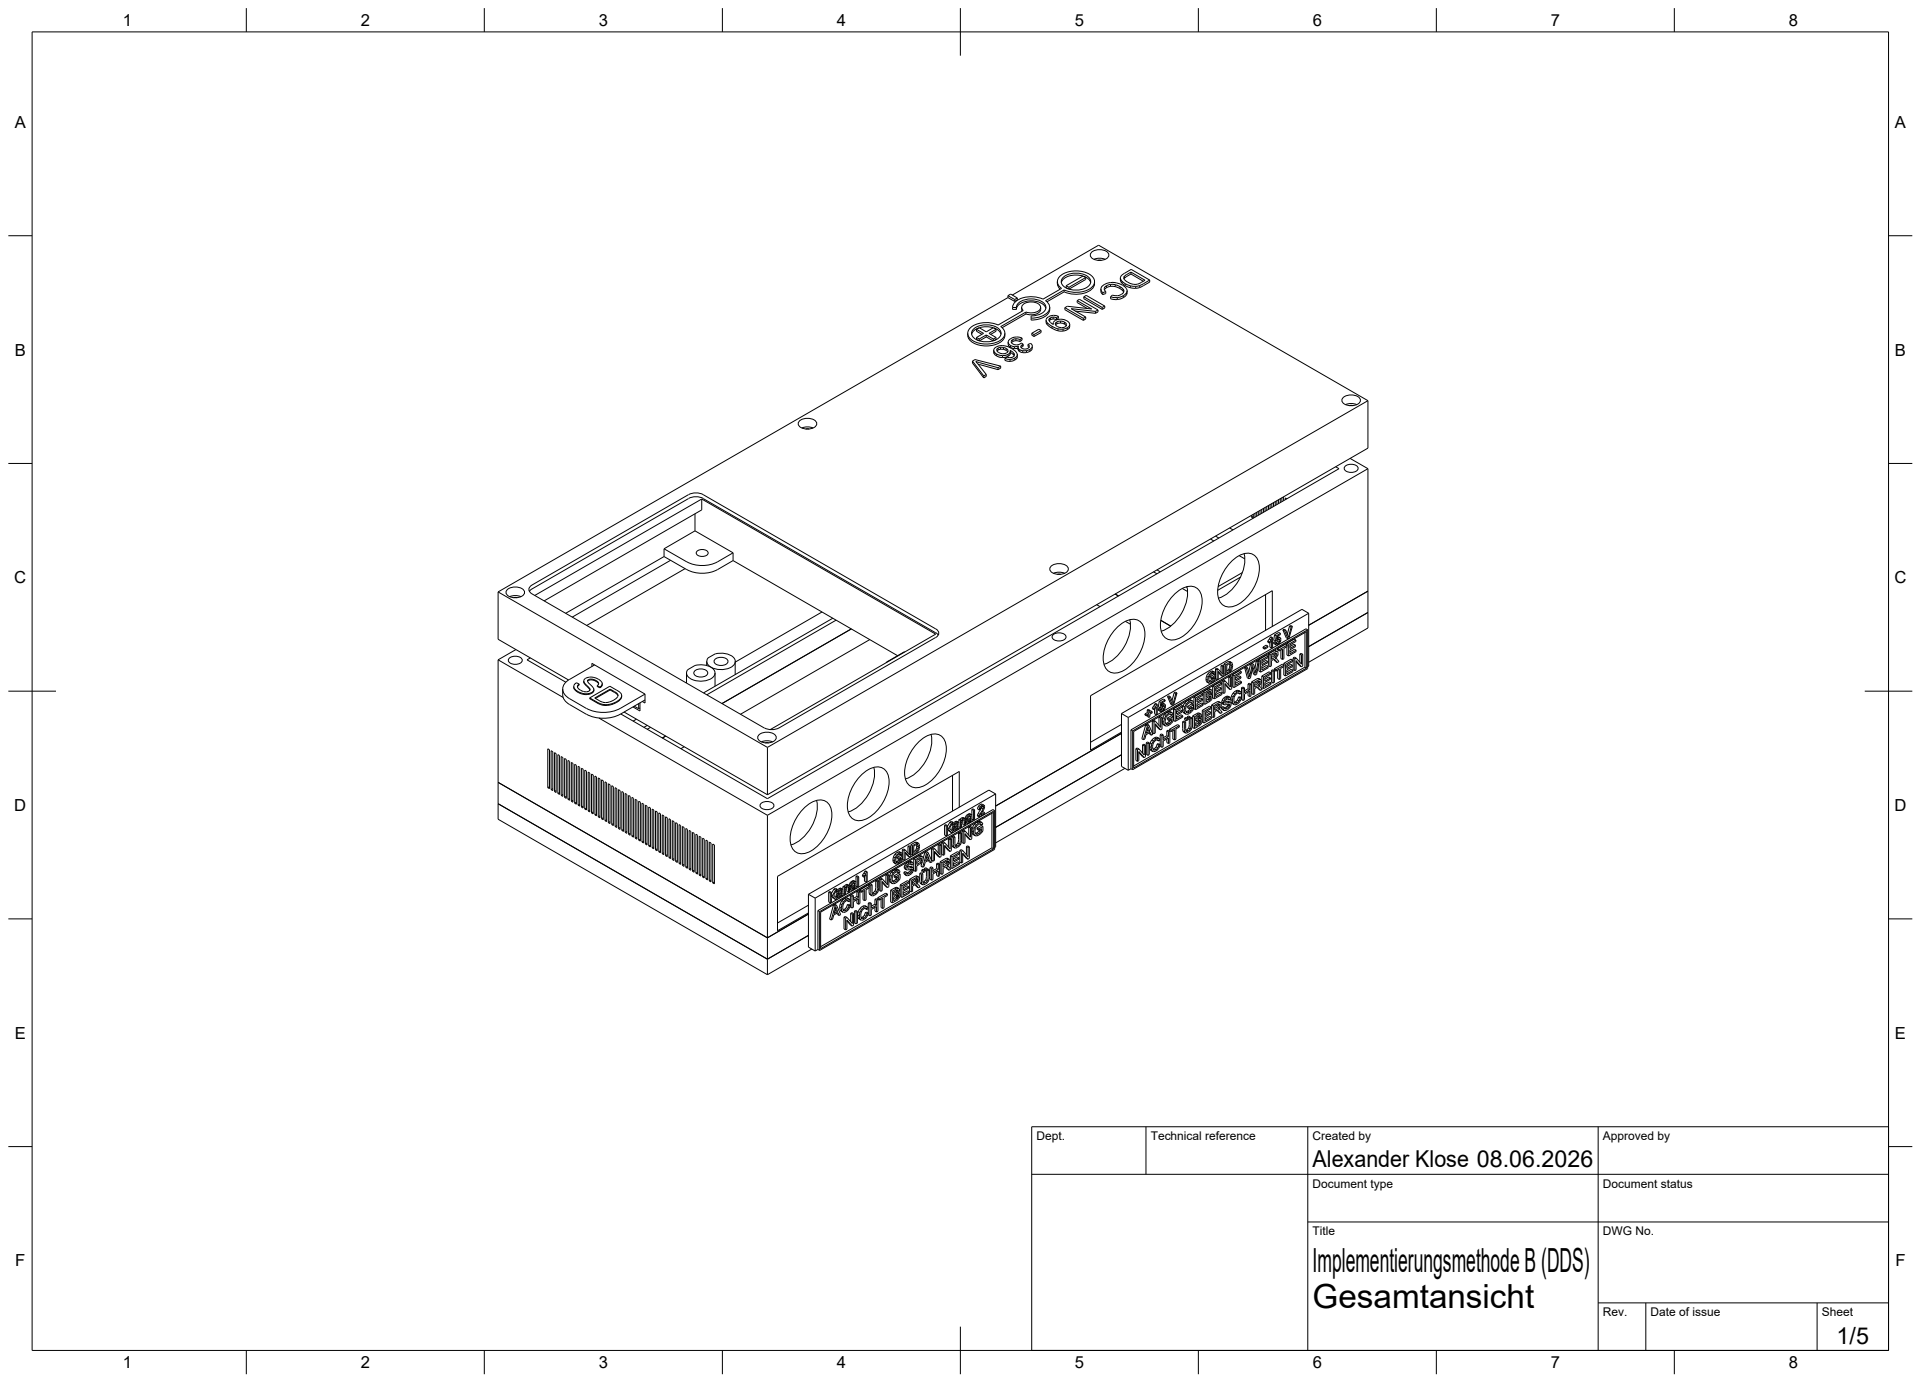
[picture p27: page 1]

Dept. | Technical reference | Created by Alexander Klose 08.06.2026 | Approved by

Document type | Document status

Title Implementierungsmethode B (DDS) Gesamtansicht | DWG No.

Rev. | Date of issue | Sheet

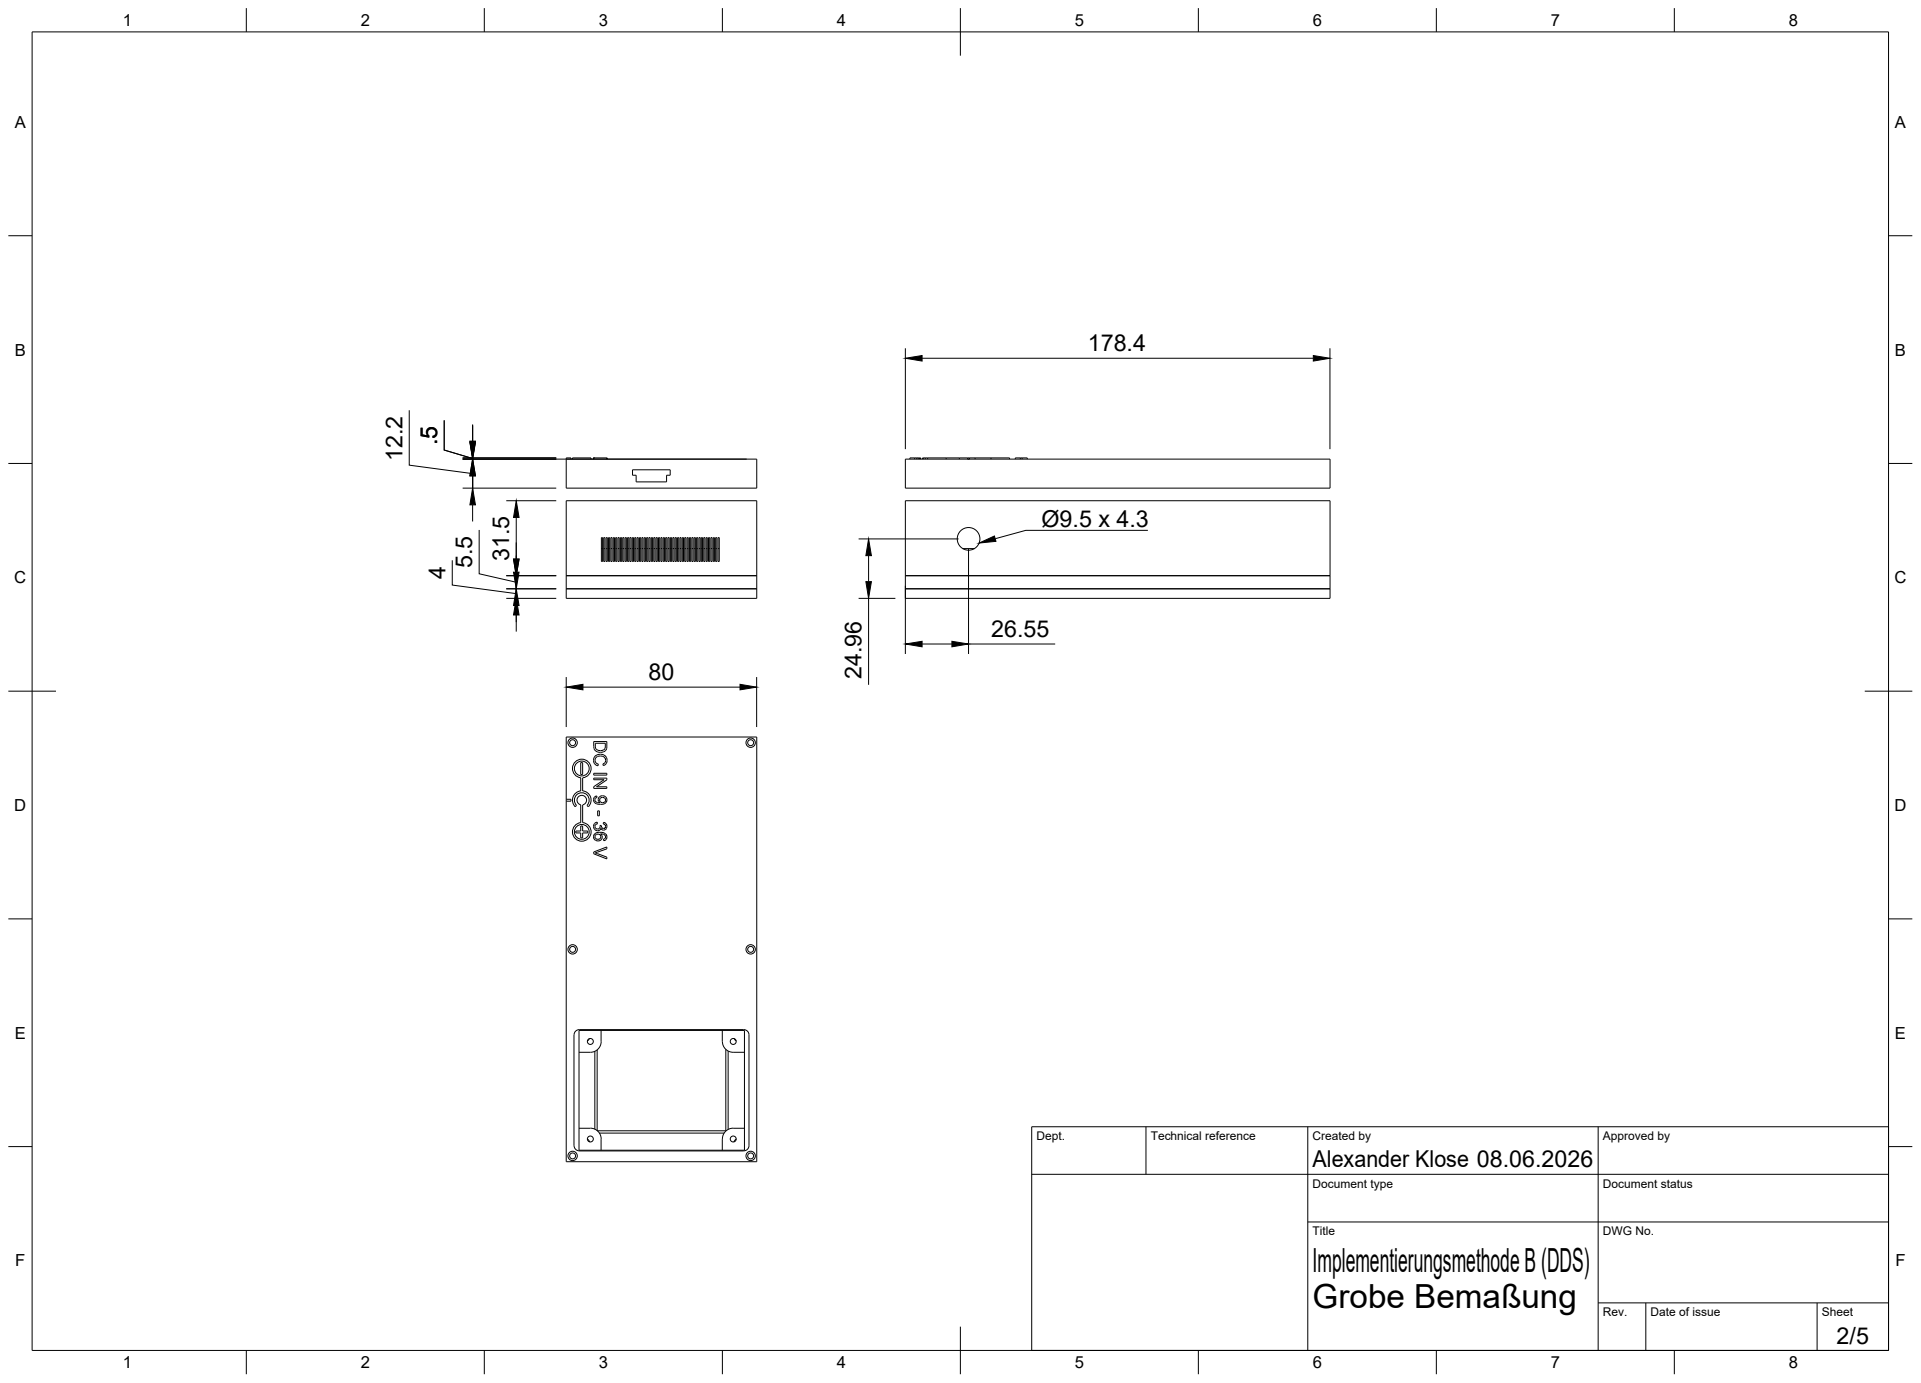
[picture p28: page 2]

Dept. | Technical reference | Created by Alexander Klose 08.06.2026 | Approved by

Document type | Document status

Title Implementierungsmethode B (DDS) Grobe Bemaßung | DWG No.

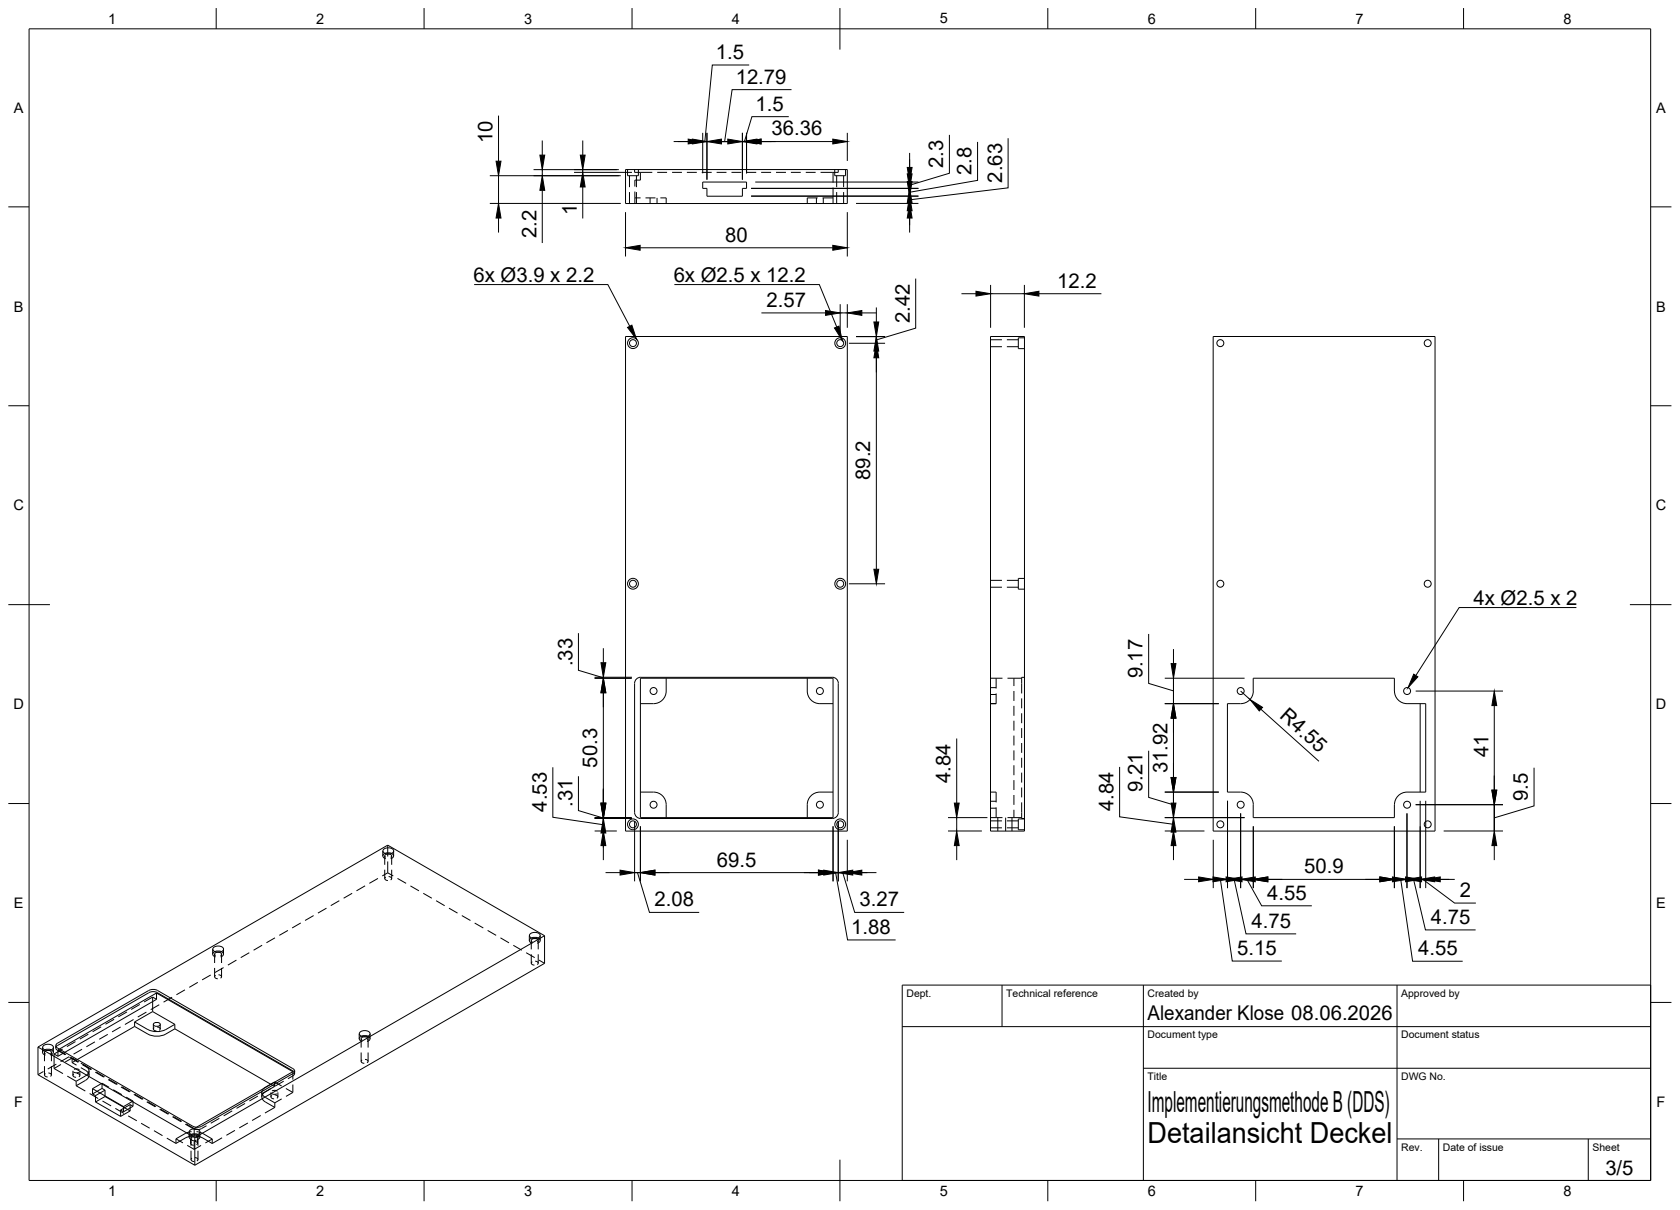
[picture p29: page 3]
Alexander Klose 2.2

Dept. | Technical reference | Created by 08.06.2026 | Approved by

Document type | Document status

Title Implementierungsmethode B (DDS) Detailansicht Deckel | DWG No.

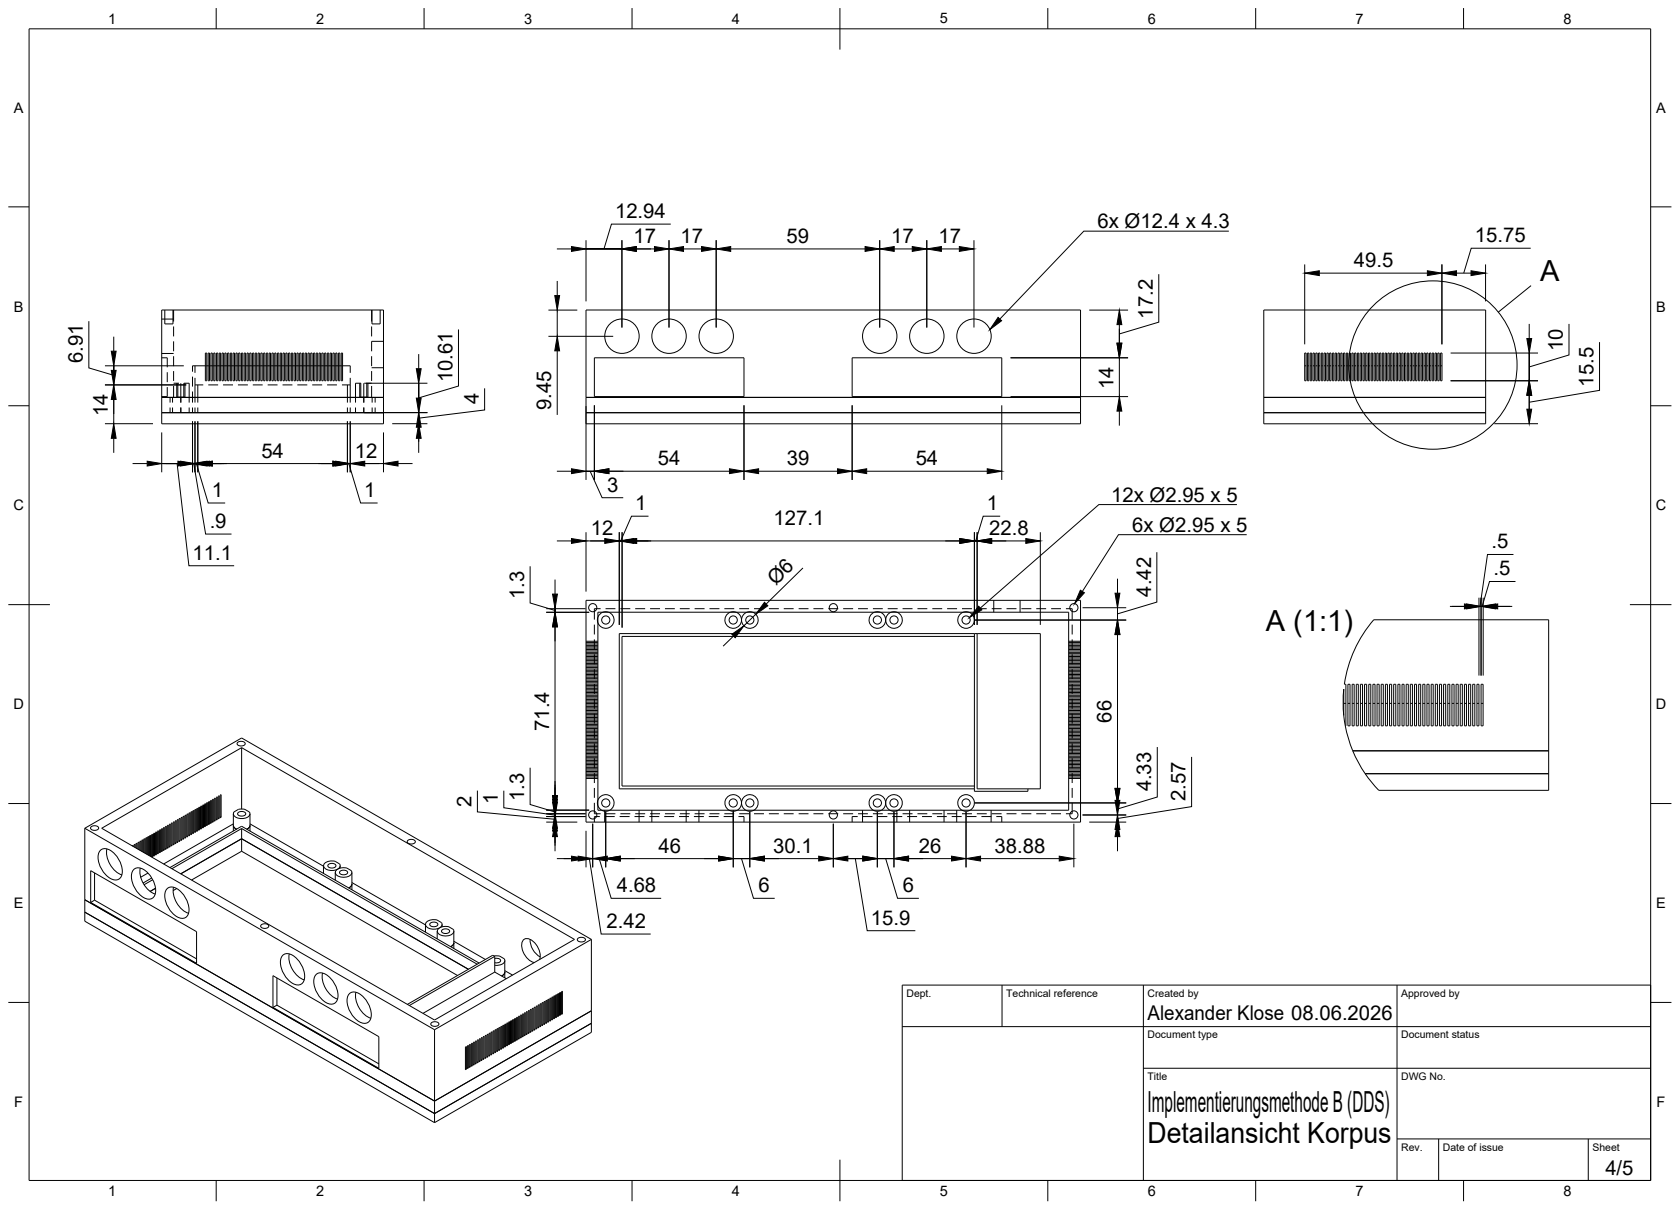
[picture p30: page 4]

Dept. | Technical reference | Created by Alexander Klose 08.06.2026 | Approved by

Document type | Document status

Title Implementierungsmethode B (DDS) Detailansicht Korpus | DWG No.

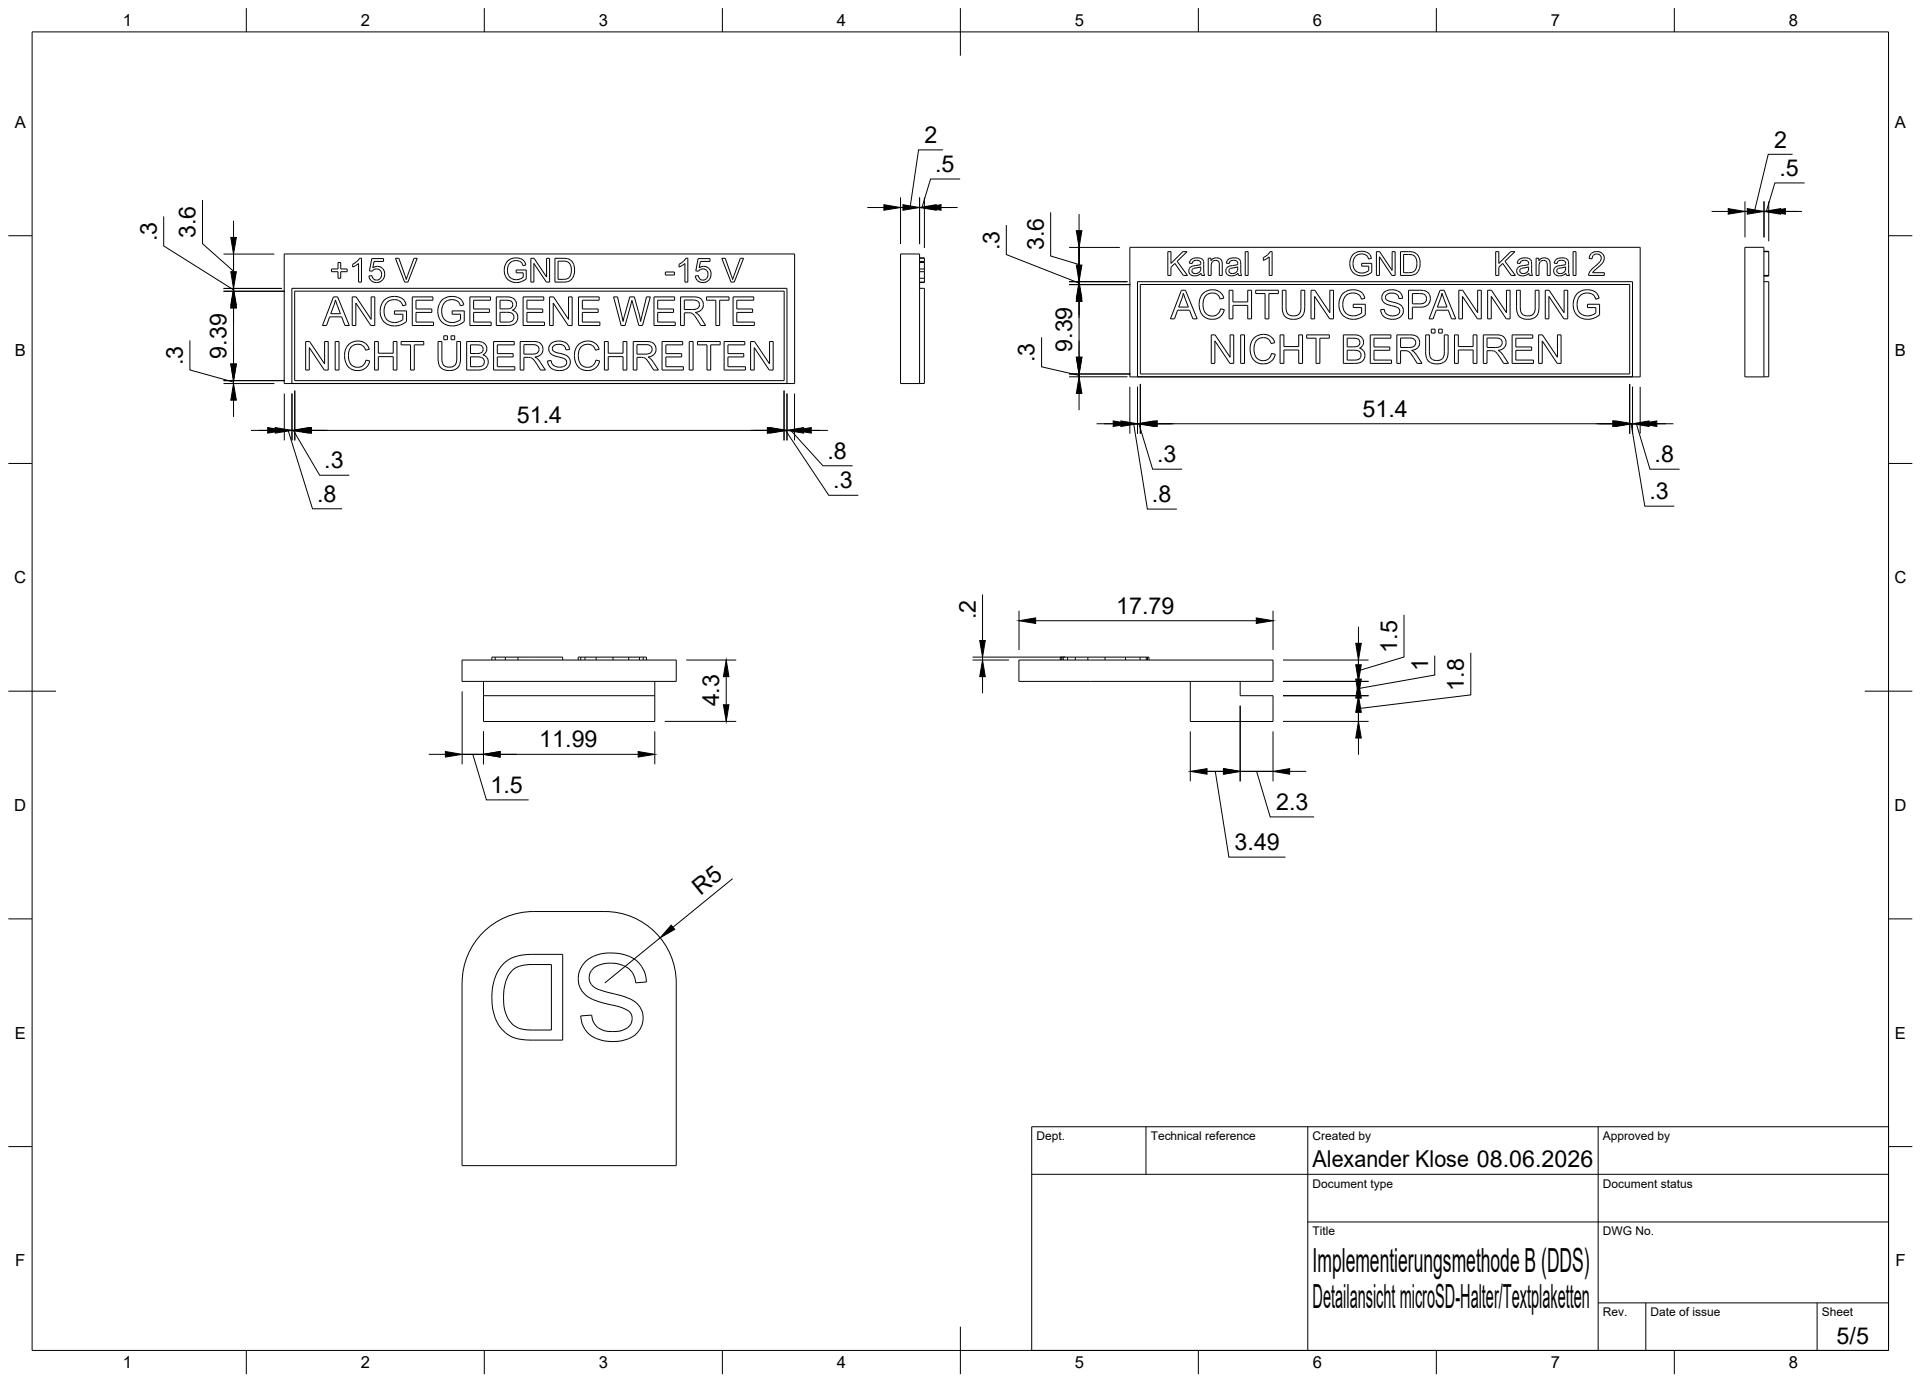
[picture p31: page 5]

Dept. | Technical reference | Created by Alexander Klose 08.06.2026 | Approved by

Document type | Document status

Title Implementierungsmethode B (DDS) Detailansicht microSD-Halter/Textplaketten | DWG No.

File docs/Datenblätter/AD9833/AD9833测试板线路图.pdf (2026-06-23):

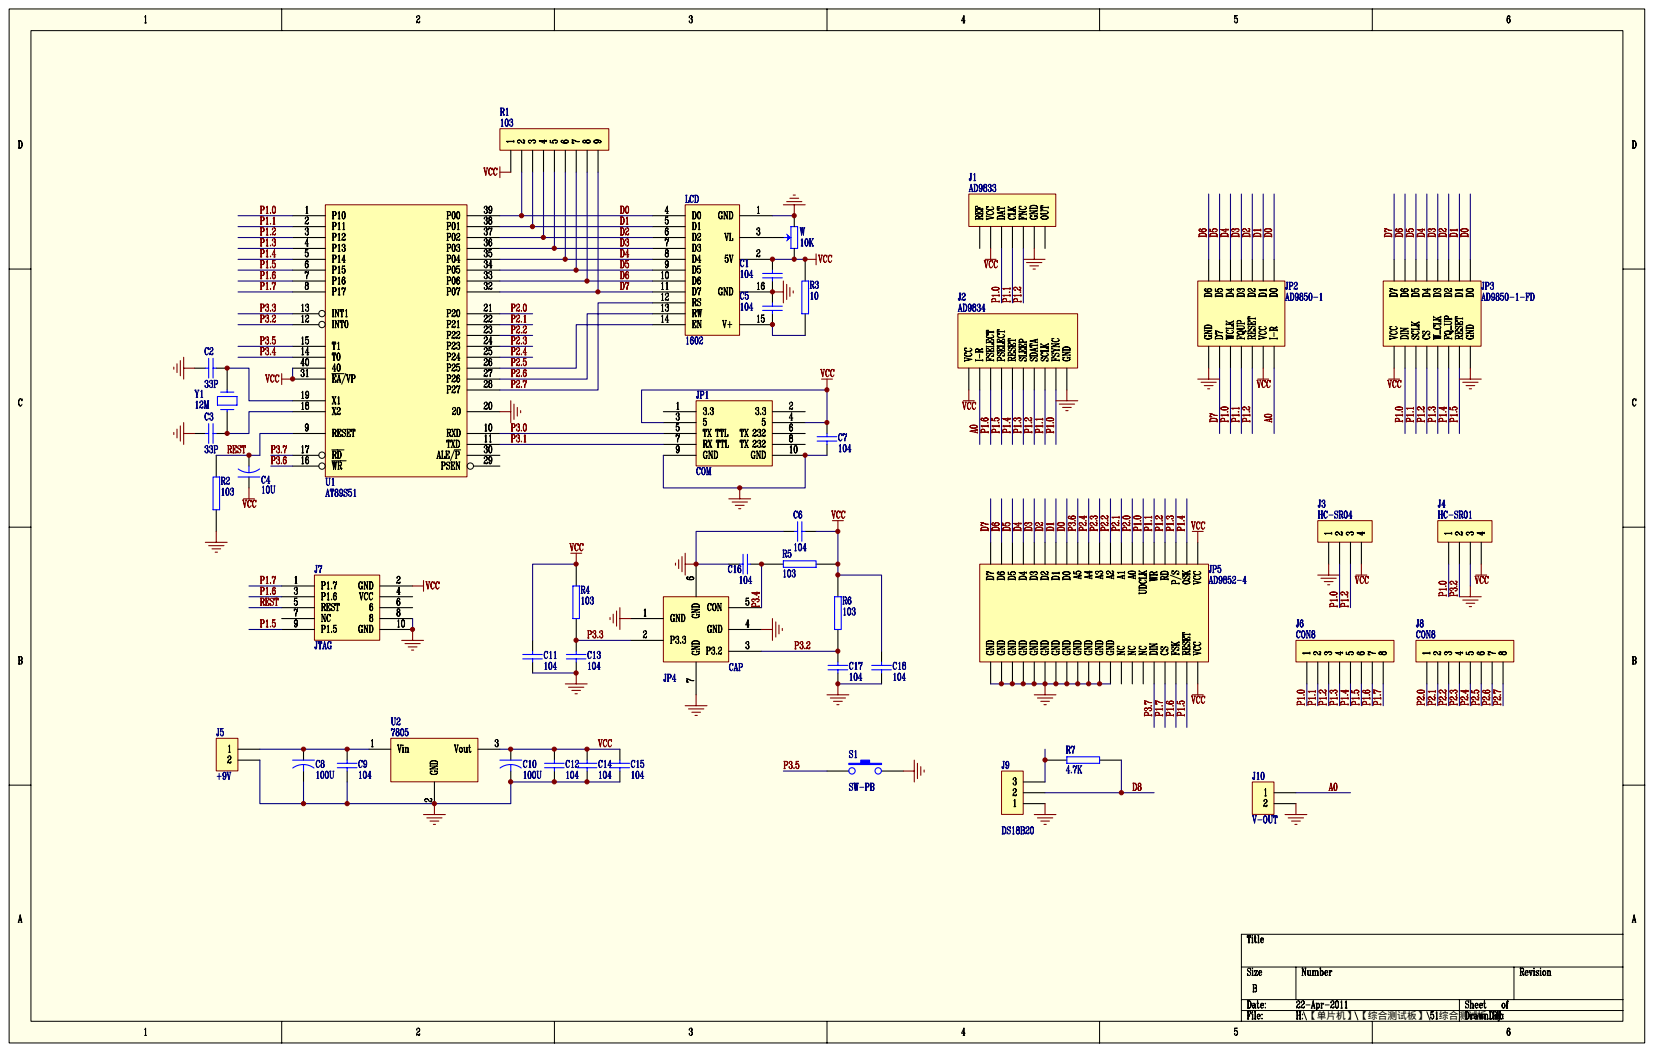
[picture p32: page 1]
【单片机】 【综合测试板】; 综合测试板

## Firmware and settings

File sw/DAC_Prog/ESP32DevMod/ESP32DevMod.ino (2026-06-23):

/**
 * @file ESP32DEVMOD.ino
 * @brief Hauptdatei des Projektes. 
 * Läd die gespeicherten Gruppen aus dem Speicher, wartet auf Signale vom ESP32S3 und erzeugt über die DAC-Pins die Funktionen
 * Ruft die essentiellen Funktionen auf und inkludiert alle benötigten Header-Dateien
 */
//----------------------------------------------------------------------
#include "signal_config.h"
#include "uart.h"
#include "save_data.h"
#include "dac_output.h"
#include "ws2812b.h"

static SignalGroup groups[MAX_GROUPS];
static uint8_t anzahl_gruppen = 0;

void setup() {
  Serial.begin(115200);
  delay(500);
  ws2812b_init();
  Serial.println("ESP32 Dev Modul gestartet");

  // Initialisieren vom NVS, laden der Gruppen
  nvs_init();
  dac_output_init();
  uart_init();

  // Ausgabe der vorhandenen Gruppen im Serial Monitor
  anzahl_gruppen = nvs_load_all(groups);
  if (anzahl_gruppen > 0) {
    Serial.printf("%u Gruppen aus NVS geladen, warte auf Startsignal.\n", anzahl_gruppen);
  }
}

void loop() {

  // Ausgeben der Funktion und warten auf Übertragung neuer Gruppen
  uart_loop();
  dac_output_loop();
}

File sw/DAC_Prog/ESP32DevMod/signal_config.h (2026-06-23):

/**
 * @file signal_config.h
 * @brief Header-Datei zur Definition der Signalkonfigurationen für die HMI-Anwendung auf dem ESP32S3.
 * Gemeinsame Typdefinitionen für ESP32S3 und ESP32 Dev Modul
 */
//----------------------------------------------------------------------
#pragma once
#include <Arduino.h>

// Parameter eines einzelnen DAC-Signals (ein Kanal)
struct SignalParams {
  float amplitude_mV;  // Amplitude in mV
  float frequency_Hz;  // Frequenz in Hz
  float phase_deg;     // Phasenversatz in DEG
  uint8_t signalType;  // Signalform (Sinus / Viereck)
};

// Eine vollständige Gruppe mit 2 Kanälen
struct SignalGroup {
  uint8_t group_id;  // Gruppennummer aus CSV  (1 - 15)
  SignalParams ch1;  // Parameter für Kanal 1
  SignalParams ch2;  // Parameter für Kanal 2
};

// Maximale Anzahl Gruppen (CSV hat 30 Einträge)
static constexpr uint8_t MAX_GROUPS = 30;

// Interner ESP32 DAC - 8-bit Auflösung (0 bis 255 Stufen)
static constexpr uint8_t DAC_RESOLUTION = 255;

// Interner ESP32 DAC - Spannungsbereich in mV
static constexpr float DAC_VOLTAGE_MIN_mV = 0.0f;
static constexpr float DAC_VOLTAGE_MAX_mV = 3000.0f;

// Interne DAC Pins des ESP32 (GPIO25 und GPIO26  DAC Pins)
static constexpr uint8_t DAC_PIN_CH1 = 25;  // DAC1 -> Kanal 1
static constexpr uint8_t DAC_PIN_CH2 = 26;  // DAC2 -> Kanal 2

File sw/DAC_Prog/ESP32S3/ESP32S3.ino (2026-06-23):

/**
 * @file ESP32S3.ino
 * @brief Hauptdatei des Projektes. 
 * Initialisiert die Hardware, lädt den Hauptbildschirm und verwaltet die Hauptschleife.
 * Ruft die essentiellen Funktionen auf und inkludiert alle benötigten Header-Dateien
 */
//----------------------------------------------------------------------
#include "Display_ST7789.h"
#include "LVGL_Driver.h"
#include "ui.h"
#include "vars.h"
#include "buzzer.h"
#include "sd_card.h"
#include "csv.h"
#include "Uart.h"

/**
 * Globaler Variablenbereich für die aktive Gruppe. Diese Variable wird verwendet, um die aktuell ausgewählte Gruppe in der Benutzeroberfläche zu verfolgen. 
 * Sie kann von anderen Teilen des Programms über die bereitgestellten Getter- und Setter-Funktionen abgerufen und geändert werden.
 */
int32_t active_group = 0;

extern "C" int32_t get_var_active_group() {
  return active_group;
}

extern "C" void set_var_active_group(int32_t value) {
  active_group = value;
}

//----------------------------------------------------------------------

/**
 * Setup-Funktion, die einmalig beim Start des Programms aufgerufen wird. Hier werden die serielle Kommunikation, die Hintergrundbeleuchtung, das LCD-Display, die LVGL-Bibliothek, die SD-Karte, die Benutzeroberfläche und der Buzzer initialisiert. 
 * Nach einer kurzen Anzeige des Startbildschirms wird der Hauptbildschirm geladen.
 * Daurauf folgend kann das HMI genutzt werden und zum Beispiel die Daten von der SD Karte kann gelesen werden
 */
void setup() {
  Serial.begin(115200);
  Backlight_Init();
  LCD_Init();
  Lvgl_Init();
  sd_init();
  ui_init();
  buzzer_init();
  uart_init();

  // ca. 500ms Starting-Screen anzeigen
  for (int i = 0; i < 50; i++) {
    Lvgl_Loop();
    delay(10);
  }
  // Hauptbildschirm laden
  loadScreen(SCREEN_ID_MAIN);
}

/**
 * Loop-Funktion, die kontinuierlich ausgeführt wird. Hier werden die LVGL-Loop-Funktion, die ui_tick-Funktion und die sd_update-Funktion aufgerufen, um die Benutzeroberfläche zu aktualisieren und den SD-Karten-Status zu überwachen. 
 */
void loop() {
  Lvgl_Loop();
  ui_tick();
  sd_update();
  vTaskDelay(pdMS_TO_TICKS(1));
}

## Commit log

2026-06-23 Dateien Hochgeladen
    [AD9833.kicad_sch, Deckel.3mf, Korpus.3mf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]
2026-07-07 Update CSV filename, SD help text and UI layout
    Change CSV filename constant in DAC and DDS builds to "/Gruppen.csv". Update SD-card help labels to show the new filename, FAT32 requirement, table format (9 columns, 30 groups) and header structure. Fix minor label text typos (e.g. "Amplitude", "Bitte Auswahl treffen") and adjust label positions/sizes. Update FGUI project UI state: selected page/tab, editor object paths, various transforms and global flow zoom/scale from 2 to 2.5, and selection flags.
2026-07-14 Fix voltage range label text
    Update label in sw/DDS_Prog/ESP32S3/screens.c (create_screen_help_grenzwerte) to read "2 V - 10 V" instead of "2 - 10 V" for clearer voltage unit presentation.
2026-07-24 Add Adafruit NeoPixel library and enable LVGL fonts
    Add complete Adafruit_NeoPixel library (v1.15.4) with support for multiple microcontroller platforms including AVR, ARM, ESP8266, ESP32, and others. Library includes core functionality for controllin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
    Also enable additional Montserrat font sizes (8, 10, 18-48) in LVGL configuration.
